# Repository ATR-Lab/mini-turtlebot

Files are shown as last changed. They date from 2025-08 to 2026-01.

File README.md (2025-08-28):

<p align="center">
  <a href="" rel="noopener">
 ATR</a>
</p>

<h3 align="center">ATR Mini TurtleBot</h3>

<div align="center">

  []() 
  []()
  

</div>

---

<p align="center"> this repo contains the steps for setup your environment and necessary source code for the Mini TurtleBot development
</p>

# Mini TurtleBot

A complete scaffold for the **MiniTurtleBot**:

- **Robot (Pico W, single radio):** drives motors, reads IMU/IR/encoders and hosts three lightweight network services:
  - **:8080** — MJPEG Stream Server (SPI/I²C camera in Turtle‑Head)
  - **:5601** — LiDAR UDP Server (newline‑delimited JSON scans)
  - **:9000** — Control TCP JSONL Server (one JSON object per line)
- **PC Side (ROS 2):** modules:
  - `tb_driver` (connects to :9000)
  - `tb_cam_client` (MJPEG only camera client)
  - `tb_lidar_client` (UDP scan parser → `sensor_msgs/LaserScan`)
  - `tb_localization` (EKF stub; plug into Nav2/SLAM as needed)
  - `tb_bringup` (launch file to start the above)
- **Scratch / ATR Bridge:** Scratch 3 extension + WebSocket bridge to ROS 2.  
  **Voice Cmd uses the PC microphone** → ATR bridge → ROS. **Robot audio (ADC→Audio Stream→TB_AUDIO_Client) is ROS‑only and not connected to Scratch**.

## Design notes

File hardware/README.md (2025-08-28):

# Hardware

This folder groups mechanical, PCB, power, and bill‑of‑materials artifacts.

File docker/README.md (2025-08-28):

# Docker

Optionally containerize the ground station (ROS 2).

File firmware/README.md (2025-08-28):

# Firmware (Pico‑W)

Reference notes for the Pico‑W implementation:
- Bring up Wi‑Fi and host three services: :8080 (MJPEG), :5601 (LiDAR UDP), :9000 (Control JSONL TCP).
- Keep handlers non‑blocking; JSONL yields simple, human‑debuggable control.
- Camera: SPI/I²C via Turtle‑Head module.

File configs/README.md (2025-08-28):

# Configs

Centralize sample configuration (e.g., `robot_host`, port overrides, topic names).

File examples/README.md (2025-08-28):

# Examples

Samples for testing and demos.

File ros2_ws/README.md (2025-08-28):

# ROS 2 Workspace

Contains client packages and bringup utilities to connect to the Pico‑W robot.

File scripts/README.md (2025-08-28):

# Scripts

Add helper scripts here (flash Pico‑W, set up ROS 2, etc.).

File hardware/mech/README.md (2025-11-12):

# Mechanical Design — Mini TurtleBot

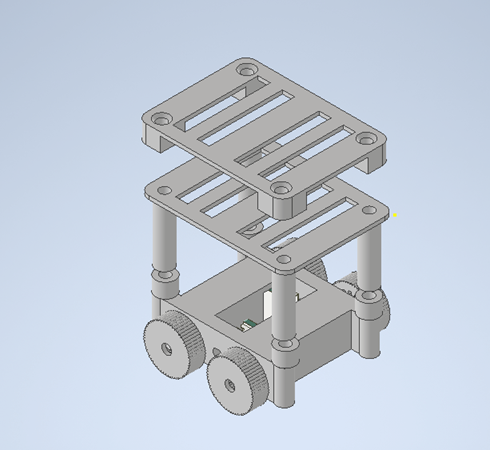
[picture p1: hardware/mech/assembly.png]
Mini TurtleBot Assembly


This folder contains the **3D printable STL files** for the Mini TurtleBot chassis and related components.  
All parts are designed to be fabricated on a standard FDM 3D printer (e.g., Prusa, Ender, Bambu Lab).  

---

## File Overview

| File | Description |
|---|---|
| `Frame.stl` | Main chassis frame that holds the Pico-W board, LiDAR, and mounting points. |
| `Battery_Base.stl` | Bottom housing for LiPo battery. |
| `Battery_Top.stl` | Top cover/retainer for the battery compartment. |
| `Gear_Wheel.stl` | Use this to print wheel and use TPU for better performance. |
| `Small_Gear12.stl` | Secondary small gear (12T) for transmission system. |
| `Small_Spacer.stl` | Spacer for aligning gears/axles. |
| `Mini_turtle_assembly.bmp` | Assembly illustration for reference (non-printable). |
| `Spur_gear_for_wheel.stl` |  Primary drive wheel gear for motor coupling. |

---

## Printing Recommendations

- **Material:** PLA+ or PETG recommended (PLA+ for easy prototyping, PETG for durability).
- **Layer Height:** 0.2 mm  
- **Infill:** 20–30% (gears: ≥40% for strength)  
- **Perimeters:** 3 walls  
- **Supports:** Only needed for `Frame.stl` (depending on printer).  
- **Orientation:**  
  - Wheels and gears: flat on build plate.  
  - Frame and battery housing: oriented upright with minimal supports.

---

## Assembly Notes

1. Print all parts and check tolerances.  
2. Attach **Gear_Wheel** and **Small_Gear12** with the provided **Small_Spacer** to motor shafts.  
3. Mount **Battery_Base** and secure the battery with **Battery_Top**.  
4. Use **Frame.stl** as the main chassis; all other parts attach onto it.  
5. Refer to `Mini_turtle_assembly.bmp` for an exploded-view style reference of how parts fit together.

---

## Customization

- Parameters such as wheel size or gear ratio can be adjusted in the source CAD files (not included here, but recommended to keep in `/hardware/mech/source/`).
- STL files are export-ready; ensure units are set to **millimeters**.

---

## License

These mechanical design files are released under the same open-source license as the rest of the Mini TurtleBot repository (MIT License).

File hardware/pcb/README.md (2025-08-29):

# PCB Design — Mini TurtleBot

This folder contains the **circuit design files** for the Mini TurtleBot platform.  
It includes the schematic, PCB layout, Gerber files, and render previews.

---

## File Overview

| File | Description |
|---|---|
| `ATR_mini_turtlebot.pdf` | PCB schematic and layout in PDF format. |
| `Gerber_atr_mini_turtlebot.zip`| Gerber package ready for PCB manufacturing (upload to your PCB fab service).|
| `.keep` | Placeholder for version control. |

---

## Design Overview

- Compact **round PCB** designed to fit the Mini TurtleBot chassis.  
- Hosts the **Raspberry Pi Pico W** module at the center.  
- Breakout connectors for:
  - **Motors & Servos** (PWM headers)  
  - **LiDAR** module  
  - **IR sensors** (IR1 / IR2)  
  - **OLED display**  
  - **MPU-6050 IMU**  
- Integrated **battery connector**, power switch, and indicator LEDs.  
- Optimized for **educational assembly** and **research prototyping**.

---

## PCB Renders

Top view with component placement:

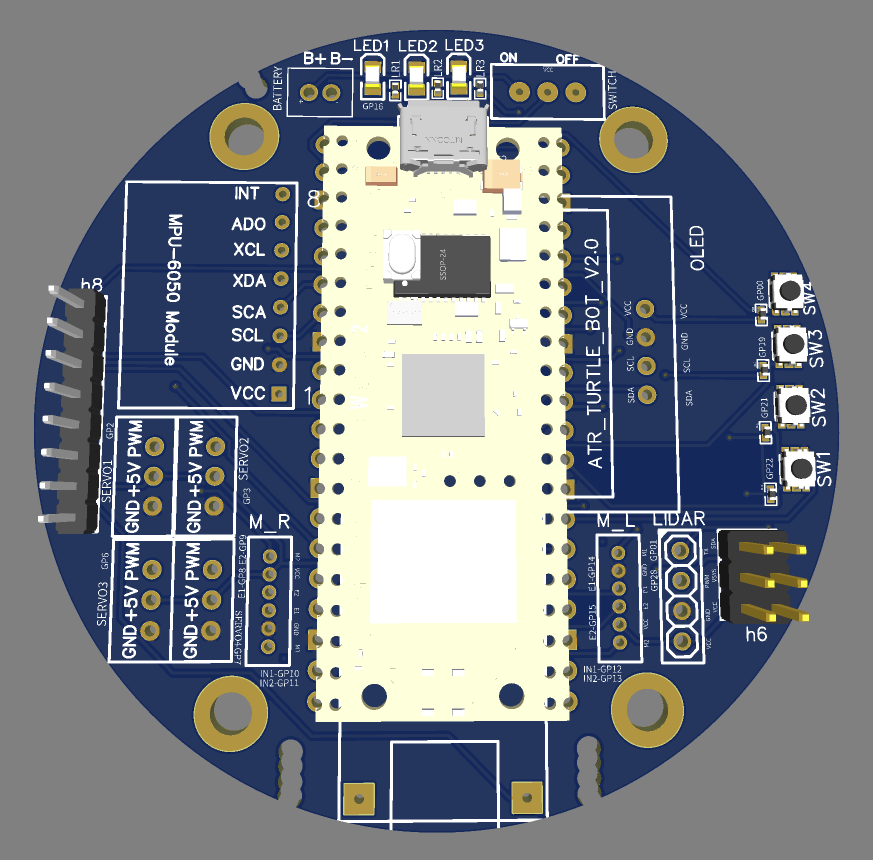
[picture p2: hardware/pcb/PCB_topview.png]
Mini TurtleBot PCB Top


3D assembled render:

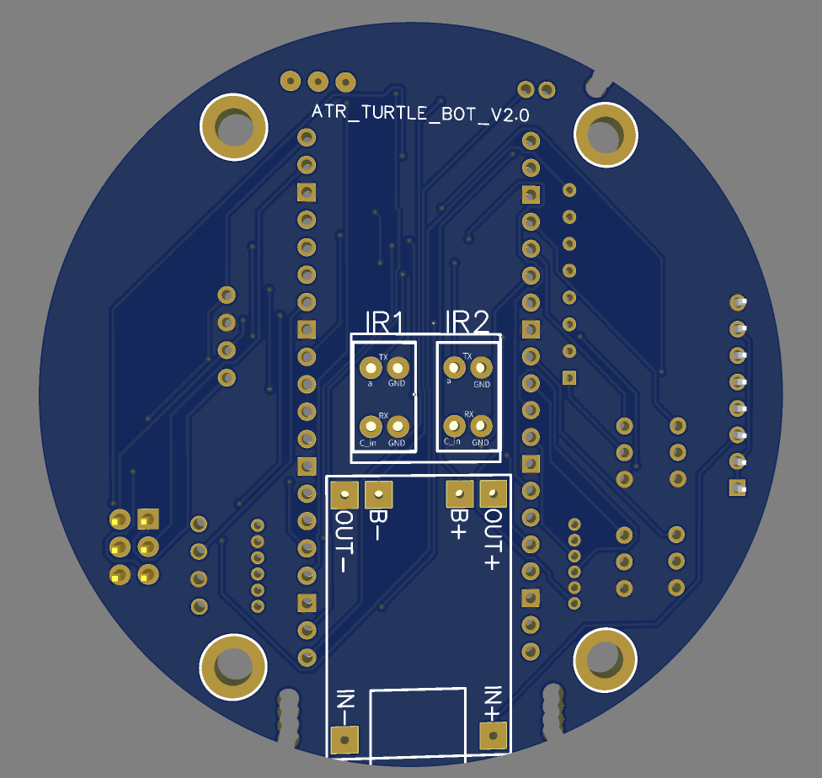
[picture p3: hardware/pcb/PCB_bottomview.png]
Mini TurtleBot PCB 3D


---

## Fabrication Notes

- **Board size:** ~75 mm circular (fits robot frame).  
- **Layers:** 2-layer PCB.  
- **Copper weight:** 1 oz copper recommended.  
- **Finish:** HASL (low cost) or ENIG (better durability).  
- **Min track/spacing:** 6/6 mil (compatible with JLCPCB, PCBWay, OSH Park).  

Upload the provided **Gerber ZIP** to a PCB manufacturer for fabrication.

---

## Assembly Notes

- Mount the **Pico W** on headers (allows easy replacement/debugging).  
- Solder motor drivers, connectors, and sensors as per schematic.  
- Pay attention to **battery polarity** and **orientation of ICs**.  
- LEDs and push buttons are optional but recommended for debugging.  

---

## Disclaimer

These PCB design files are provided **as-is** for educational and research use.  
Always verify footprints and component orientation before ordering boards.

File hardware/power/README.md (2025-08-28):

# Power Notes

- Single battery powers Pico‑W + sensors. Design for brown‑out resilience.
- Keep camera MJPEG pipeline lightweight to save power and bandwidth.

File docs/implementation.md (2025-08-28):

# Implementation

## Robot (Pico‑W)
- MicroPython or C SDK may be used. Minimal services:
  - **JSONL Control (TCP :9000):** Commands: `ping`, `set_speed`, `imu` (examples).
  - **MJPEG Server (HTTP :8080):** Stub OK; replace with your camera driver.
  - **LiDAR UDP (:5601):** Send scans as newline‑delimited JSON for simplicity.
- On‑robot modules: Camera Sensor Frame Buffer → Vision → MJPEG server; Motor Management; On‑robot Localization (optional); Battery Management; Config.

## Ground Station (ROS 2)
- `tb_driver`: converts `/cmd_vel` to left/right and talks JSONL over TCP.
- `tb_cam_client`: pulls MJPEG, publishes `sensor_msgs/Image`.
- `tb_lidar_client`: parses UDP JSON → `sensor_msgs/LaserScan`.
- `tb_localization`: EKF stub compatible with Nav2; plug your filter (e.g., robot_localization) via params in `tb_localization/config/ekf.yaml`.
- `tb_bringup`: one‑shot launch for all clients; parameters for robot host/ports.

## Scratch / ATR Bridge
- WebSocket bridge converts Scratch intents (from PC mic) into ROS topics.
- No link between TB_AUDIO_Client and Scratch. Audio remains ROS‑only.

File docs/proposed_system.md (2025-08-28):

# Proposed System

## Overview
A **single-radio Pico‑W** robot handles motor control, IMU/IR/encoders, and battery while exposing three network services:

- **Control TCP JSONL (:9000):** Text-based control/telemetry. Each line is a JSON object, e.g. `{ "cmd": "set_speed", "left": 0.2, "right": 0.2 }`.
- **MJPEG Stream (:8080):** HTTP multipart stream of JPEG frames from the Turtle‑Head camera (SPI/I²C). **MJPEG‑only** by design.
- **LiDAR UDP (:5601):** Newline‑delimited JSON arrays of `[angle_deg, distance_m]` pairs.

The **Ground Station (ROS 2)** runs: `tb_driver`, `tb_cam_client`, `tb_lidar_client`, `tb_localization (EKF)`, with optional `Odometry/SLAM` and `Nav2`.

The **Scratch Interface + ATR Bridge** lives on the PC. The **PC microphone** is used for Voice Commands that are translated to ROS topics and then to the robot via `tb_driver`. Robot audio does **not** connect to Scratch.

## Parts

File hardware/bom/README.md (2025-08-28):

# BOM

Track part numbers, vendors, and costs here. Include motors, motor drivers, LiDAR, SPI/I²C camera module, batteries, charger/PMIC, and chassis parts.

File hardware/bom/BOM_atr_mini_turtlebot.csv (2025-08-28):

ID | Name | Designator | Footprint | Quantity | Manufacturer Part | Manufacturer | Supplier | Supplier Part | Price | Pins | JLCPCB Part Class
1 | PHR-2 | BATTERY | JST_PHR-2 | 1 |  |  |  |  |  | 2
2 | 1kΩ | BR1,BR2,BR3,BR4,LR1,LR2,LR3 | R0402 | 7 | 0402WGF1001TCE | UNI-ROYAL(厚声) | LCSC | C11702 | 0.001 | 2 | Basic Part
3 | DRIVER | D | SSOP-24_L8.4-W5.8-P0.65-LS7.8-BL | 1 | TB6612FNG(O,C,8,EL | TOSHIBA(东芝) | LCSC | C88224 | 1.251 | 24 | Extended Part
4 | 100nF | DC1 | CAP-SMD_L3.2-W1.6-RD | 1 | CA45-A-35V-0.1UF-K | CEC(振华新云) | LCSC | C2976900 | 0.114 | 2 | Extended Part
5 | 10uF | DC2 | CASE-B_3528 | 1 | CA45-B-25V-10uF-K | CEC(振华新云) | LCSC | C128259 | 0.114 | 2 | Extended Part
6 | 10kΩ | DR1,IR1-R1,IR2-R1 | R0805 | 3 | SCR0805J10K | VO(翔胜) | LCSC | C5140188 | 0.001 | 2
7 | Header-Male-2.54_2x3 | H6 | HDR-TH_6P-P2.54-V-M-R2-C3-S2.54-1 | 1 | 2.54-2*3P针 | BOOMELE(博穆精密) | LCSC | C65114 | 0.03 | 6 | Extended Part
8 | Z-211-0811-0021-001 | H8 | HDR-TH_8P-P2.54-V-M | 1 | Z-211-0811-0021-001 | Nextron(正凌) | LCSC | C190820 | 0.041 | 8 | Extended Part
9 | TCRT5000L | IR1 | ATR_BASE | 1 | TCRT5000L | VISHAY | LCSC | C24085 | 1.183 | 4
10 | 300Ω | IR1-R2,IR2-R2 | R0603 | 2 | WR06X3000FTL | Walsin(华新科) | LCSC | C163899 | 0.001 | 2 | Extended Part
11 | TCRT5000L | IR2 | ATR_BASE_22 | 1 | TCRT5000L | VISHAY | LCSC | C24085 | 1.183 | 4
12 | 17-21SUYC/TR8 | LED1,LED2 | LED0805-R-RD | 2 | KT-0805黄灯 | KENTO | LCSC | C2296 | 0.012 | 2 | Basic Part
13 | 17-215VGC/TR8 | LED3 | LED0805-R-RD | 1 | 17-215VGC/TR8 | EVERLIGHT(亿光) | LCSC | C264426 | 0.07 | 2 | Extended Part
14 | MPU-6050 Module | MPU6050 | MPU-6050 MODULE | 1 |  |  |  |  |  | 8
15 | JST ZH 6pin | M_L,M_R | JST ZH 6PIN CONNECTOR 1.5MM_ATR | 2 | JST ZH 6pin |  | RS-Online | 762-0780 |  | 6
16 | SSD1306-128x64-OLED-SPI | OLED | SSD1306_DISPLAY-I2C | 1 |  |  |  |  |  | 4
17 | RPi-pico | RPI-PICO | PICO2W_V3.0_ATR_ATR | 1 |  |  |  |  |  | 40
18 | Servo | SERVO1,SERVO2,SERVO3,SERVO4 | SERVO | 4 |  |  |  |  |  | 3
19 | GT-TC171B-H014-L1 | SW1,SW2,SW3,SW4 | SW-SMD_4P-L3.0-W2.7-P1.66-LS3.5 | 4 | GT-TC171B-H014-L1 | G-Switch(品赞) | LCSC | C843620 | 0.116 | 6 | Extended Part
20 | SLIDE SWITCH DPDT 1P2T JB (LARGE HOLES) | SWITCH | SLIDE SWITCH DPDT 1P2T JB | 1 | New SchematicLib |  |  |  |  | 3
21 | LIDAR | U6 | LIDAR SENSER | 1 |  |  |  |  |  | 4

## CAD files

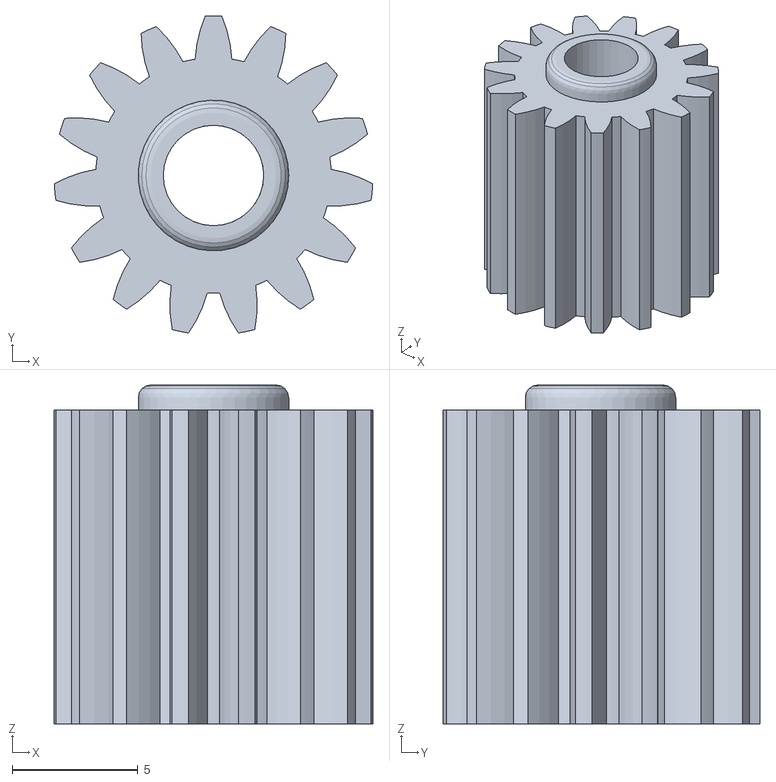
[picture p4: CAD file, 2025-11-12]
hardware/mech/Spur Gear for wheel.stl
12.7 x 12.6 x 13.5

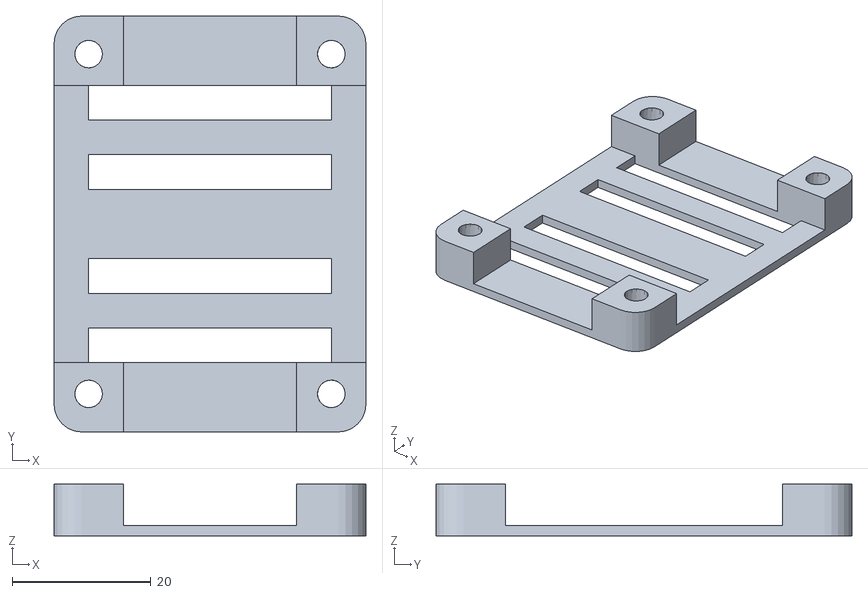
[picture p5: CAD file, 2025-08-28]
hardware/mech/Battery_Top.stl
45.0 x 60.0 x 7.50

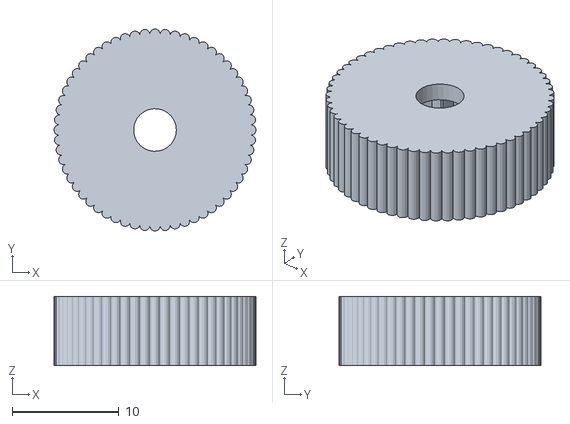
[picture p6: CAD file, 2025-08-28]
hardware/mech/Gear_Wheel.stl
18.9 x 18.9 x 6.50

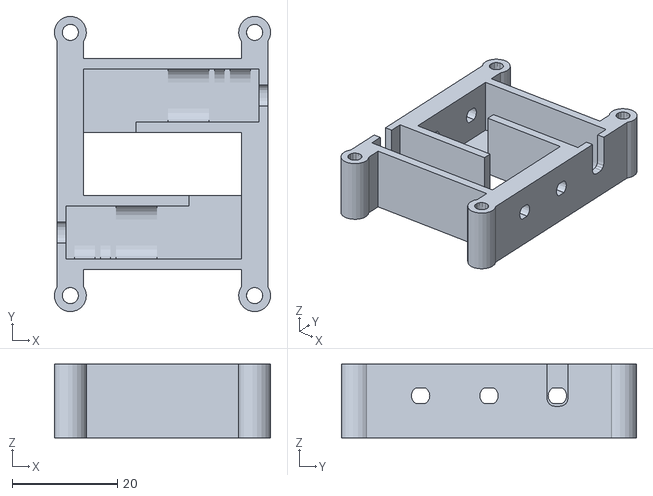
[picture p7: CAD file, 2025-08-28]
hardware/mech/Frame.stl
41.1 x 56.0 x 14.0

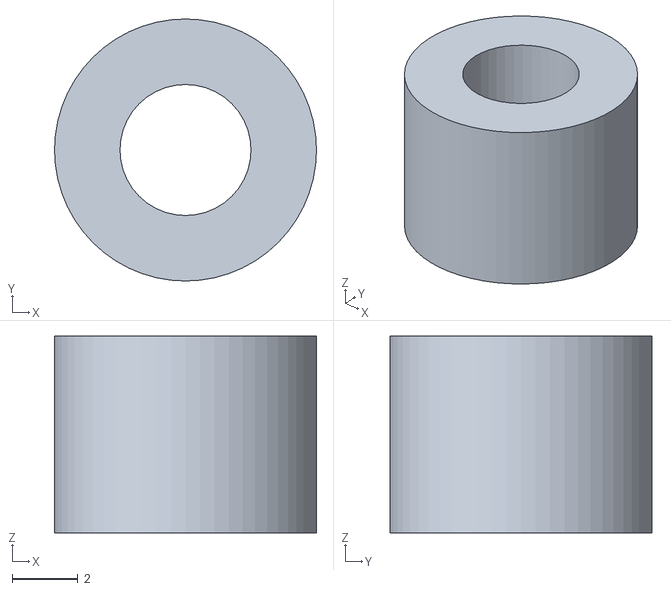
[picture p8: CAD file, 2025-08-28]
hardware/mech/Small Spacer.stl
8.00 x 8.00 x 6.00

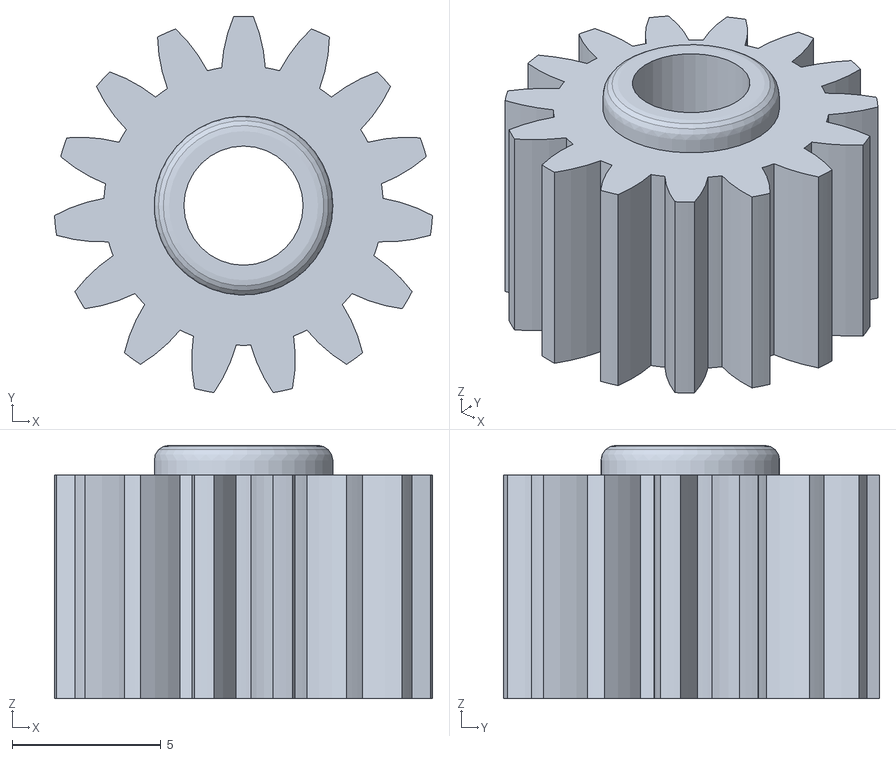
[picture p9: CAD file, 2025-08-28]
hardware/mech/Small_Gear12.stl
12.7 x 12.6 x 8.50

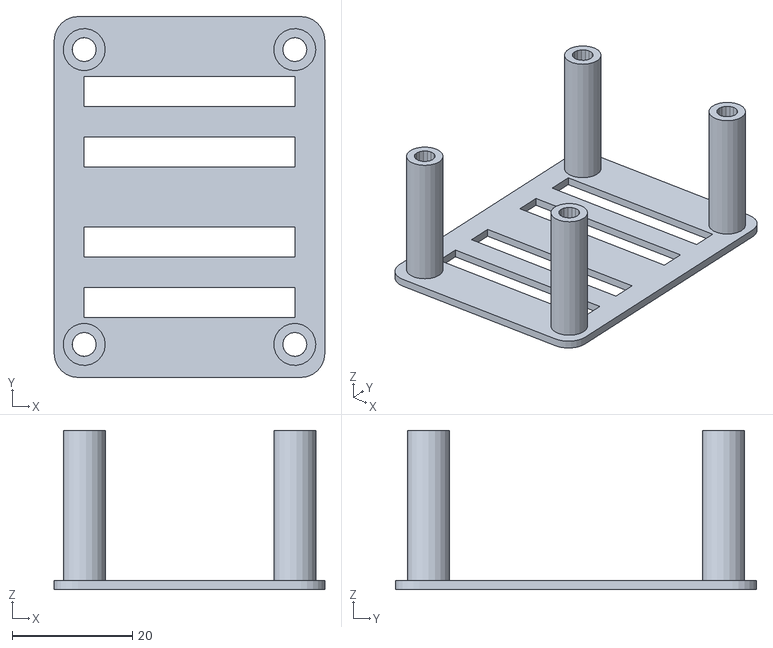
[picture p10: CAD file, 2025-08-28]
hardware/mech/Battery_Base.stl
45.0 x 60.0 x 26.5

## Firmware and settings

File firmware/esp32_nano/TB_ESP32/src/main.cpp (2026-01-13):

#include <WiFi.h>
#include <ESPAsyncWebServer.h>
#include <AsyncTCP.h>
#include <ArduinoJson.h>
#include <Wire.h>

#include <Adafruit_GFX.h>
#include <Adafruit_SSD1306.h>

// -------------------- USER CONFIG --------------------
static const char* WIFI_SSID = "Shaon";
static const char* WIFI_PASS = "shA12345";
static const uint16_t WS_PORT = 9000;

// Robot kinematics (tune these)
static const float WHEEL_BASE_M = 0.10f;  // distance between wheels (m) - adjust
// -----------------------------------------------------

// -------------------- PINOUT (from schematic) --------------------
// DRV8835 inputs (IN/IN style, two pins per motor)
static const int PIN_MTA1 = A6;   // MTA1 -> A6
static const int PIN_MTA2 = A7;   // MTA2 -> A7
static const int PIN_MTB1 = D8;   // MTB1 -> D8
static const int PIN_MTB2 = D9;   // MTB2 -> D9

// OLED I2C pins (from schematic)
static const int PIN_SDA  = A4;   // SDA -> A4
static const int PIN_SCL  = A5;   // SCL -> A5
// -----------------------------------------------------------------

// -------------------- OLED --------------------
static const int OLED_W = 128;
static const int OLED_H = 64;
static const int OLED_RST = -1;
Adafruit_SSD1306 display(OLED_W, OLED_H, &Wire, OLED_RST);

// -------------------- Web Server / WS --------------------
AsyncWebServer server(WS_PORT);
AsyncWebSocket ws("/ws"); // WS endpoint

// -------------------- Motor PWM (ESP32 LEDC) --------------------
static const int PWM_FREQ = 20000;     // 20kHz
static const int PWM_RES  = 10;        // 10-bit => 0..1023
static const int PWM_MAX  = (1 << PWM_RES) - 1;

static const int CH_A1 = 0;
static const int CH_A2 = 1;
static const int CH_B1 = 2;
static const int CH_B2 = 3;

volatile uint32_t last_cmd_ms = 0;
static const uint32_t CMD_TIMEOUT_MS = 500;

// Track last PWM actually applied (for motor_state stream)
static volatile int g_left_pwm = 0;
static volatile int g_right_pwm = 0;

// -------------------- Stream gating (cfg) --------------------
struct StreamCfg {
  bool en = false;
  float hz = 0.0f;
  uint32_t period_ms = 0;
  uint32_t last_ms = 0;
};

static StreamCfg g_stream_motors;
static StreamCfg g_stream_imu;
static StreamCfg g_stream_ir;
static StreamCfg g_stream_lidar;
static StreamCfg g_stream_lidar360;

// Defaults if cfg sets hz <= 0
static const float DEF_MOTORS_HZ   = 20.0f;
static const float DEF_IMU_HZ      = 50.0f;
static const float DEF_IR_HZ       = 10.0f;
static const float DEF_LIDAR_HZ    = 5.0f;
static const float DEF_LIDAR360_HZ = 5.0f;

// -------------------- MPU6050 (raw I2C, no extra library) --------------------
static const uint8_t MPU_ADDR = 0x68;

// MPU registers
static const uint8_t REG_PWR_MGMT_1 = 0x6B;
static const uint8_t REG_ACCEL_XOUT_H = 0x3B;

// Scale factors for default config:
// Accel ±2g => 16384 LSB/g
// Gyro  ±250 dps => 131 LSB/(deg/s)
static const float ACC_LSB_PER_G = 16384.0f;
static const float GYRO_LSB_PER_DPS = 131.0f;
static const float G_TO_MSS = 9.80665f;
static const float DEG_TO_RAD_F = 0.017453292519943295f;

// -------------------- helpers ----------
static int dutyFromNorm(float x) {
  x = fabsf(x);
  if (x > 1.0f) x = 1.0f;
  return (int)(x * PWM_MAX);
}

// IN/IN style: one pin PWM for forward, the other PWM for reverse
static void setMotorININ(int ch_fwd, int ch_rev, float speed_norm) {
  int duty = dutyFromNorm(speed_norm);

  if (speed_norm >= 0.0f) {
    ledcWrite(ch_fwd, duty);
    ledcWrite(ch_rev, 0);
  } else {
    ledcWrite(ch_fwd, 0);
    ledcWrite(ch_rev, duty);
  }
}

static void stopAll() {
  ledcWrite(CH_A1, 0);
  ledcWrite(CH_A2, 0);
  ledcWrite(CH_B1, 0);
  ledcWrite(CH_B2, 0);

  g_left_pwm = 0;
  g_right_pwm = 0;
}

static void drawStatus(const char* line2 = nullptr) {
  display.clearDisplay();
  display.setTextSize(1);
  display.setRotation(2);
  display.setTextColor(SSD1306_WHITE);

  display.setCursor(0, 0);
  display.print("Mini Turtlebot");

  display.setCursor(0, 12);
  display.print("SSID: ");
  display.print(WIFI_SSID);

  display.setCursor(0, 24);
  display.print("IP: ");
  display.print(WiFi.localIP());

  display.setCursor(0, 36);
  display.print("WS: ");
  display.print(WS_PORT);
  display.print("  /ws");

  if (line2) {
    display.setCursor(0, 52);
    display.print(line2);
  }

  display.display();
}

static void setStream(StreamCfg& s, bool en, float hz, float def_hz) {
  s.en = en;
  s.hz = (hz > 0.0f) ? hz : def_hz;
  if (!s.en) {
    s.period_ms = 0;
    return;
  }
  float used = (s.hz > 0.0f) ? s.hz : def_hz;
  s.period_ms = (uint32_t)max(1.0f, 1000.0f / used);
  s.last_ms = millis();
}

// -------------------- Robot control --------------------
static void handleCmdVel(float linear_x, float angular_z) {
  // differential drive:
  float v_left  = linear_x - angular_z * (WHEEL_BASE_M * 0.5f);
  float v_right = linear_x + angular_z * (WHEEL_BASE_M * 0.5f);

  // Map to normalized [-1..1]
  const float VMAX = 0.25f; // tune
  float left_norm  = v_left  / VMAX;
  float right_norm = v_right / VMAX;

  if (left_norm >  1.0f) left_norm =  1.0f;
  if (left_norm < -1.0f) left_norm = -1.0f;
  if (right_norm >  1.0f) right_norm =  1.0f;
  if (right_norm < -1.0f) right_norm = -1.0f;

  // Motor A = left, Motor B = right (swap if needed)
  setMotorININ(CH_A1, CH_A2, left_norm);
  setMotorININ(CH_B1, CH_B2, -right_norm);

  g_left_pwm  = (int)(left_norm  * PWM_MAX);
  g_right_pwm = (int)(right_norm * PWM_MAX);

  last_cmd_ms = millis();
}

// -------------------- WS JSONL helpers --------------------
static void wsTextAllJsonl(const JsonDocument& doc) {
  String out;
  serializeJson(doc, out);
  out += "\n";
  ws.textAll(out);
}

static void wsTextClientJsonl(AsyncWebSocketClient* client, const JsonDocument& doc) {
  if (!client) return;
  String out;
  serializeJson(doc, out);
  out += "\n";
  client->text(out);
}

// -------------------- MPU6050 low-level --------------------
static bool mpuWriteReg(uint8_t reg, uint8_t value) {
  Wire.beginTransmission(MPU_ADDR);
  Wire.write(reg);
  Wire.write(value);
  return (Wire.endTransmission() == 0);
}

static bool mpuReadBytes(uint8_t startReg, uint8_t* buf, size_t n) {
  Wire.beginTransmission(MPU_ADDR);
  Wire.write(startReg);
  if (Wire.endTransmission(false) != 0) return false;

  size_t got = Wire.requestFrom((int)MPU_ADDR, (int)n, (int)true);
  if (got != n) return false;

  for (size_t i = 0; i < n; i++) buf[i] = Wire.read();
  return true;
}

static bool mpuInit() {
  // Wake up MPU6050 (clear sleep bit)
  // PWR_MGMT_1 = 0x00
  if (!mpuWriteReg(REG_PWR_MGMT_1, 0x00)) {
    return false;
  }
  delay(50);
  return true;
}

static bool mpuReadAccelGyro(float& ax_mss, float& ay_mss, float& az_mss,
                             float& gx_rads, float& gy_rads, float& gz_rads) {
  uint8_t b[14];
  if (!mpuReadBytes(REG_ACCEL_XOUT_H, b, sizeof(b))) return false;

  int16_t ax = (int16_t)((b[0] << 8) | b[1]);
  int16_t ay = (int16_t)((b[2] << 8) | b[3]);
  int16_t az = (int16_t)((b[4] << 8) | b[5]);
  // temp: b[6..7] ignored
  int16_t gx = (int16_t)((b[8] << 8) | b[9]);
  int16_t gy = (int16_t)((b[10] << 8) | b[11]);
  int16_t gz = (int16_t)((b[12] << 8) | b[13]);

  // Convert accel to m/s^2
  ax_mss = ((float)ax / ACC_LSB_PER_G) * G_TO_MSS;
  ay_mss = ((float)ay / ACC_LSB_PER_G) * G_TO_MSS;
  az_mss = ((float)az / ACC_LSB_PER_G) * G_TO_MSS;

  // Convert gyro to rad/s
  float gx_dps = ((float)gx / GYRO_LSB_PER_DPS);
  float gy_dps = ((float)gy / GYRO_LSB_PER_DPS);
  float gz_dps = ((float)gz / GYRO_LSB_PER_DPS);

  gx_rads = gx_dps * DEG_TO_RAD_F;
  gy_rads = gy_dps * DEG_TO_RAD_F;
  gz_rads = gz_dps * DEG_TO_RAD_F;

  return true;
}

// -------------------- Periodic publishers --------------------
static void publishHeartbeat() {
  static uint32_t last_ms = 0;
  static uint32_t i = 0;
  uint32_t now = millis();
  if (now - last_ms < 1000) return;
  last_ms = now;

  StaticJsonDocument<192> hb;
  hb["v"] = 1;
  hb["type"] = "hb";
  hb["ts_ms"] = now;
  hb["i"] = i++;
  wsTextAllJsonl(hb);
}

static void publishMotorsIfDue() {
  if (!g_stream_motors.en || g_stream_motors.period_ms == 0) return;
  uint32_t now = millis();
  if (now - g_stream_motors.last_ms < g_stream_motors.period_ms) return;
  g_stream_motors.last_ms = now;

  StaticJsonDocument<256> m;
  m["v"] = 1;
  m["type"] = "state";
  m["state"] = "motors";
  m["ts_ms"] = now;

  // placeholders until you have encoders
  m["left_rads"] = 0.0f;
  m["right_rads"] = 0.0f;
  m["left_pwm"] = (int)g_left_pwm;
  m["right_pwm"] = (int)g_right_pwm;

  wsTextAllJsonl(m);
}

static void publishImuIfDue() {
  if (!g_stream_imu.en || g_stream_imu.period_ms == 0) return;
  uint32_t now = millis();
  if (now - g_stream_imu.last_ms < g_stream_imu.period_ms) return;
  g_stream_imu.last_ms = now;

  float ax, ay, az, gx, gy, gz;
  if (!mpuReadAccelGyro(ax, ay, az, gx, gy, gz)) {
    // Don't spam; just skip if read fails
    return;
  }

  StaticJsonDocument<256> j;
  j["v"] = 1;
  j["type"] = "state";
  j["state"] = "imu";
  j["ts_ms"] = now;

  // accel (m/s^2)
  j["ax"] = ax;
  j["ay"] = ay;
  j["az"] = az;

  // gyro (rad/s)
  j["gx"] = gx;
  j["gy"] = gy;
  j["gz"] = gz;

  wsTextAllJsonl(j);
}

// -------------------- cfg handler --------------------
static void handleCfg(AsyncWebSocketClient* client, const JsonDocument& doc) {
  int id = doc["id"] | 0;

  JsonObjectConst sObj = doc["streams"].as<JsonObjectConst>();
  if (sObj.isNull()) {
    StaticJsonDocument<192> ack;
    ack["v"] = 1;
    ack["type"] = "ack";
    ack["id"] = id;
    ack["ok"] = false;
    ack["msg"] = "missing streams object";
    wsTextClientJsonl(client, ack);
    return;
  }

  auto upd = [&](const char* name, StreamCfg& cfg, float defhz) {
    if (!sObj[name].is<JsonObjectConst>()) return;
    JsonObjectConst o = sObj[name].as<JsonObjectConst>();
    bool en = o["en"] | false;
    float hz = o["hz"] | 0.0f;
    setStream(cfg, en, hz, defhz);
  };

  upd("motors",   g_stream_motors,   DEF_MOTORS_HZ);
  upd("imu",      g_stream_imu,      DEF_IMU_HZ);
  upd("ir",       g_stream_ir,       DEF_IR_HZ);
  upd("lidar",    g_stream_lidar,    DEF_LIDAR_HZ);
  upd("lidar360", g_stream_lidar360, DEF_LIDAR360_HZ);

  StaticJsonDocument<192> ack;
  ack["v"] = 1;
  ack["type"] = "ack";
  ack["id"] = id;
  ack["ok"] = true;
  ack["msg"] = "streams updated";
  wsTextClientJsonl(client, ack);
}

// -------------------- Message dispatcher (one JSON line) --------------------
static void handleOneJsonLine(AsyncWebSocketClient* client, const String& line) {
  if (line.length() == 0) return;

  // cfg has nested objects, give enough space
  StaticJsonDocument<768> doc;
  DeserializationError err = deserializeJson(doc, line);
  if (err) {
    Serial.printf("[ws] JSON parse error: %s\n", err.c_str());
    return;
  }

  const char* type_s = doc["type"] | "";
  const char* cmd_s  = doc["cmd"]  | "";

  if (strcmp(type_s, "cmd") == 0) {
    if (strcmp(cmd_s, "vel") == 0) {
      float linear  = doc["linear"]  | 0.0f;
      float angular = doc["angular"] | 0.0f;
      handleCmdVel(linear, angular);
    } else if (strcmp(cmd_s, "stop") == 0) {
      stopAll();
    } else if (strcmp(cmd_s, "estop") == 0) {
      bool enabled = doc["enabled"] | true;
      if (enabled) stopAll();
    } else if (strcmp(cmd_s, "ping") == 0) {
      StaticJsonDocument<128> ack;
      ack["v"] = 1;
      ack["type"] = "ack";
      ack["ok"] = true;
      ack["msg"] = "pong";
      wsTextClientJsonl(client, ack);
    } else {
      Serial.printf("[ws] unknown cmd: %s\n", cmd_s);
    }
  }
  else if (strcmp(type_s, "cfg") == 0) {
    handleCfg(client, doc);
  }
  // Optional backward compatibility
  else if (strcmp(type_s, "cmd_vel") == 0) {
    float linear  = doc["linear_x"]  | 0.0f;
    float angular = doc["angular_z"] | 0.0f;
    handleCmdVel(linear, angular);
  }
  else {
    Serial.printf("[ws] unknown msg type: %s\n", type_s);
  }
}

// -------------------- WS events --------------------
void onWsEvent(AsyncWebSocket* server_,
               AsyncWebSocketClient* client,
               AwsEventType type,
               void* arg,
               uint8_t* data,
               size_t len) {
  (void)server_;
  (void)arg;

  if (type == WS_EVT_CONNECT) {
    Serial.printf("[ws] client #%u connected\n", client->id());
    drawStatus("WS client connected");
    return;
  }
  if (type == WS_EVT_DISCONNECT) {
    Serial.printf("[ws] client #%u disconnected\n", client->id());
    drawStatus("WS client disconnected");
    stopAll();
    return;
  }
  if (type != WS_EVT_DATA) return;

  AwsFrameInfo* info = (AwsFrameInfo*)arg;
  if (!info->final || info->index != 0 || info->len != len) return;
  if (info->opcode != WS_TEXT) return;

  // Copy into String
  String msg;
  msg.reserve(len + 1);
  for (size_t i = 0; i < len; i++) msg += (char)data[i];

  // JSONL: handle one or multiple lines
  int start = 0;
  while (start < (int)msg.length()) {
    int end = msg.indexOf('\n', start);
    if (end < 0) end = msg.length();
    String line = msg.substring(start, end);
    line.trim();
    start = end + 1;
    if (line.length() == 0) continue;
    handleOneJsonLine(client, line);
  }
}

void setup() {
  Serial.begin(115200);
  delay(200);
  Serial.println("\n[boot] Mini Turtlebot ESP32");

  // I2C OLED + IMU share the same bus
  Wire.begin(PIN_SDA, PIN_SCL); // SDA=A4, SCL=A5

  if (!display.begin(SSD1306_SWITCHCAPVCC, 0x3C)) {
    Serial.println("[oled] SSD1306 init failed");
  } else {
    drawStatus("Booting...");
  }

  // Init MPU6050
  if (mpuInit()) {
    Serial.println("[imu] MPU6050 init OK");
  } else {
    Serial.println("[imu] MPU6050 init FAIL (check wiring/address)");
  }

  // PWM setup
  ledcSetup(CH_A1, PWM_FREQ, PWM_RES);
  ledcSetup(CH_A2, PWM_FREQ, PWM_RES);
  ledcSetup(CH_B1, PWM_FREQ, PWM_RES);
  ledcSetup(CH_B2, PWM_FREQ, PWM_RES);

  ledcAttachPin(PIN_MTA1, CH_A1);
  ledcAttachPin(PIN_MTA2, CH_A2);
  ledcAttachPin(PIN_MTB1, CH_B1);
  ledcAttachPin(PIN_MTB2, CH_B2);

  stopAll();

  // Default streams: motors ON at 1Hz so you can see it, imu OFF by default
  setStream(g_stream_motors, true,  1.0f, DEF_MOTORS_HZ);
  setStream(g_stream_imu,    false, 0.0f, DEF_IMU_HZ);
  setStream(g_stream_ir,     false, 0.0f, DEF_IR_HZ);
  setStream(g_stream_lidar,  false, 0.0f, DEF_LIDAR_HZ);
  setStream(g_stream_lidar360, false, 0.0f, DEF_LIDAR360_HZ);

  // WiFi
  WiFi.mode(WIFI_STA);
  WiFi.begin(WIFI_SSID, WIFI_PASS);

  Serial.print("[wifi] connecting");
  while (WiFi.status() != WL_CONNECTED) {
    delay(250);
    Serial.print(".");
  }
  Serial.println();
  Serial.print("[wifi] connected, IP=");
  Serial.println(WiFi.localIP());

  drawStatus("WiFi connected");

  // WebSocket at /ws
  ws.onEvent(onWsEvent);
  server.addHandler(&ws);

  // Simple landing page at /
  server.on("/", HTTP_GET, [](AsyncWebServerRequest* request) {
    request->send(200, "text/plain", "Mini Turtlebot WS server. Use ws://<ip>:9000/ws");
  });

  server.begin();
  Serial.printf("[server] listening on http://0.0.0.0:%u/\n", WS_PORT);
  Serial.printf("[ws] ws://<ip>:%u/ws\n", WS_PORT);

  last_cmd_ms = millis();
}

void loop() {
  ws.cleanupClients();

  uint32_t now = millis();

  // Always-on heartbeat
  publishHeartbeat();

  // Gated streams
  publishMotorsIfDue();
  publishImuIfDue();

  // SAFETY WATCHDOG — STOP ONLY IF STALE
  static bool already_stopped = false;
  if ((now - last_cmd_ms) > CMD_TIMEOUT_MS) {
    if (!already_stopped) {
      Serial.printf("[SAFETY] cmd timeout (%lu ms) -> STOP\n",
                    (unsigned long)(now - last_cmd_ms));
      stopAll();
      already_stopped = true;
    }
  } else {
    already_stopped = false;
  }

  delay(5); // faster loop helps stream timing
}

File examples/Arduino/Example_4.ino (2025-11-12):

#include <Arduino.h>
#include <Wire.h>
#include <Adafruit_GFX.h>
#include <Adafruit_SSD1306.h>

// ---------- I2C ----------
#define SDA_PIN A4
#define SCL_PIN A5

// ---------- OLED ----------
#define SCREEN_WIDTH 128
#define SCREEN_HEIGHT 64
#define OLED_RESET -1
Adafruit_SSD1306 display(SCREEN_WIDTH, SCREEN_HEIGHT, &Wire, OLED_RESET);

// ---------- MOTOR DRIVER ----------
#define MTA1 A6
#define MTA2 A7
#define MTB1 D8
#define MTB2 D9

// ---------- ENCODER PINS ----------
#define MEA1 D10
#define MEA2 D11
#define MEB1 D12
#define MEB2 D13

// ---------- PWM CONFIG ----------
const int pwmFreq = 500;
const int pwmResolution = 10;
const int pwmA1_Ch = 0;
const int pwmA2_Ch = 1;
const int pwmB1_Ch = 2;
const int pwmB2_Ch = 3;

// ---------- Encoder & Motion ----------
volatile long encoderCountA = 0;
volatile long encoderCountB = 0;
volatile uint8_t prevStateA = 0, prevStateB = 0;

// ---------- Encoder Settings ----------
const int ticksPerRev = 12 * 4;  // 12 ticks per channel, 4x decoding
const float gearRatio = 30.0;     // Update if gear reduction is used

#define READ_ENC_A() ((digitalRead(MEA1) << 1) | digitalRead(MEA2))
#define READ_ENC_B() ((digitalRead(MEB1) << 1) | digitalRead(MEB2))

// ---------- ISR ----------
void IRAM_ATTR handleEncoderA() {
  uint8_t state = READ_ENC_A();
  uint8_t combo = (prevStateA << 2) | state;
  switch (combo) {
    case 0b0001: case 0b0111: case 0b1110: case 0b1000: encoderCountA++; break;
    case 0b0010: case 0b0100: case 0b1101: case 0b1011: encoderCountA--; break;
  }
  prevStateA = state;
}

void IRAM_ATTR handleEncoderB() {
  uint8_t state = READ_ENC_B();
  uint8_t combo = (prevStateB << 2) | state;
  switch (combo) {
    case 0b0001: case 0b0111: case 0b1110: case 0b1000: encoderCountB++; break;
    case 0b0010: case 0b0100: case 0b1101: case 0b1011: encoderCountB--; break;
  }
  prevStateB = state;
}

// ---------- Motor PWM ----------
int motorPowerA = 500;  // Range -1023 to 1023; Initial Min +- 165, Dynamic Min +-90
int motorPowerB = 500;  // Range -1023 to 1023; Initial Min +- 165, Dynamic Min +-90

void setMotorA(int pwm) {
  pwm = constrain(pwm, -1023, 1023);
  if (pwm >= 0) {
    ledcWrite(pwmA1_Ch, pwm);
    ledcWrite(pwmA2_Ch, 0);
  } else {
    ledcWrite(pwmA1_Ch, 0);
    ledcWrite(pwmA2_Ch, -pwm);
  }
}

void setMotorB(int pwm) {
  pwm = constrain(pwm, -1023, 1023);
  if (pwm >= 0) {
    ledcWrite(pwmB1_Ch, 0);
    ledcWrite(pwmB2_Ch, pwm);
  } else {
    ledcWrite(pwmB1_Ch, -pwm);
    ledcWrite(pwmB2_Ch, 0);
  }
}

void setupEncoderInterrupt(){
  pinMode(MEA1, INPUT); pinMode(MEA2, INPUT);
  pinMode(MEB1, INPUT); pinMode(MEB2, INPUT);
  prevStateA = READ_ENC_A();
  prevStateB = READ_ENC_B();
  attachInterrupt(digitalPinToInterrupt(MEA1), handleEncoderA, CHANGE);
  attachInterrupt(digitalPinToInterrupt(MEA2), handleEncoderA, CHANGE);
  attachInterrupt(digitalPinToInterrupt(MEB1), handleEncoderB, CHANGE);
  attachInterrupt(digitalPinToInterrupt(MEB2), handleEncoderB, CHANGE);
}

void setupMotorPWM(){
  ledcSetup(pwmA1_Ch, pwmFreq, pwmResolution);
  ledcSetup(pwmA2_Ch, pwmFreq, pwmResolution);
  ledcSetup(pwmB1_Ch, pwmFreq, pwmResolution);
  ledcSetup(pwmB2_Ch, pwmFreq, pwmResolution);
  ledcAttachPin(MTA1, pwmA1_Ch);
  ledcAttachPin(MTA2, pwmA2_Ch);
  ledcAttachPin(MTB1, pwmB1_Ch);
  ledcAttachPin(MTB2, pwmB2_Ch);
}

void setup() {
  Serial.begin(115200);
  Serial.setTimeout(20);
  Wire.begin(SDA_PIN, SCL_PIN);
  display.begin(SSD1306_SWITCHCAPVCC, 0x3C);
  display.clearDisplay();

  setupEncoderInterrupt();
  setupMotorPWM();

  // Run Motors
  setMotorA(motorPowerA); // 'motorPowerA' range is -1023 to 1023
  setMotorB(motorPowerB); // 'motorPowerB' range is -1023 to 1023
}

void loop() {
  static long lastCountA = 0, lastCountB = 0;
  static unsigned long lastTime = 0;

  unsigned long now = millis();
  if (now - lastTime >= 100) {
    long deltaA = encoderCountA - lastCountA;
    long deltaB = encoderCountB - lastCountB;
    lastCountA = encoderCountA;
    lastCountB = encoderCountB;

    float ticksPerSecA = deltaA * 10.0;
    float ticksPerSecB = deltaB * 10.0;

    float rpmA = (ticksPerSecA * 60.0) / (ticksPerRev * gearRatio);
    float rpmB = (ticksPerSecB * 60.0) / (ticksPerRev * gearRatio);

    // Display on OLED
    display.clearDisplay();
    display.setCursor(0, 0);
    display.setTextSize(1);
    display.setRotation(2);
    display.setTextColor(SSD1306_WHITE);
    display.printf("Motor A: %s\n", rpmA >= 0 ? "REV" : "FWD");
    display.printf("RPM: %.1f\n", fabs(rpmA));
    display.printf("Motor B: %s\n", rpmB >= 0 ? "FWD" : "REV");
    display.printf("RPM: %.1f\n", fabs(rpmB));
    display.display();

    lastTime = now;
  }

  // Serial input: "A 600" or "B -500"
  if (Serial.available()) {
    char motor = Serial.read();
    int value = Serial.parseInt();
    if (motor == 'A') {
      motorPowerA = value;
      setMotorA(motorPowerA);
    } else if (motor == 'B') {
      motorPowerB = value;
      setMotorB(motorPowerB);
    }
    // flush remaining
    while (Serial.available()) Serial.read();
  }
}

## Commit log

2025-08-28 mech design init
    [Battery_Base.stl, Battery_Top.stl, Frame.stl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]
2025-08-28 PCB init
    [BOM_atr_mini_turtlebot.csv]
2025-08-29 pcb readme added
2025-09-03 Gear for wheel with space
    [Spur Gear for wheel.stl]
2025-11-12 Arduino example added
2026-01-13 motor state and IMU working

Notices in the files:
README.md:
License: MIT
